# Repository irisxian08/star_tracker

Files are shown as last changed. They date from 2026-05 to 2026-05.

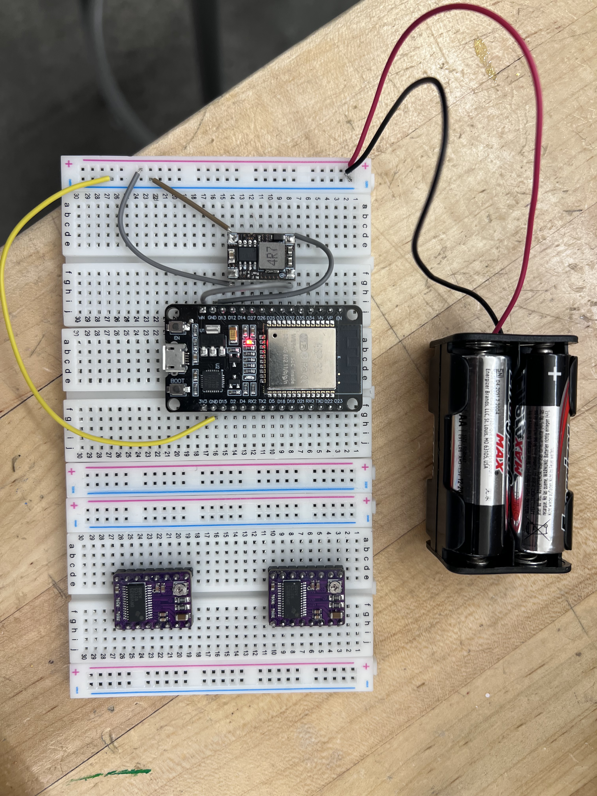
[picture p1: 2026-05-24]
photos/breadboard_testing.jpg

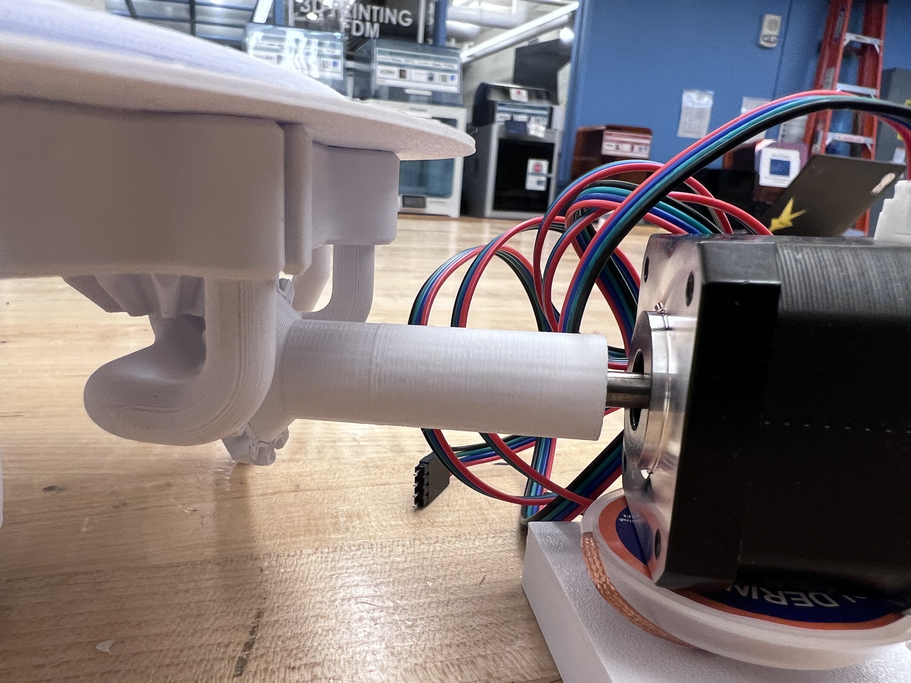
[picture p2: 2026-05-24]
photos/azimuth_motor_close_up.jpg

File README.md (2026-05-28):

# Star Tracker Project

## PLEASE READ BEFORE STARTING PROJECT

---

## Introduction

This project is a motorized alt-azimuth star tracker/pointing system designed to rotate toward celestial coordinates using two stepper motors controlled by an ESP32 microcontroller. The long-term goal is to create a low-cost, modular system capable of automatically pointing a laser (and potentially a camera or telescope) toward astronomical targets using coordinate conversion algorithms and motorized movement.

The project combines mechanical design, electronics, soldering, embedded programming, and astronomical coordinate systems into a single integrated system. While the current version is still a prototype and several hardware issues remain unresolved, the project documents the full design process, including successful subsystems, failed attempts, debugging notes, and lessons learned.

This repository includes CAD models, wiring diagrams, motor-control code, calibration/error-detection ideas, troubleshooting notes, and engineering/design reflections. The goal of the repository is not just to show a finished build, but to document the actual engineering process behind building a system like this from scratch.

---

## Repository Navigation

### Main Files

- [Parts List](parts_list.xlsx)
- [Sources and References](sources.docx)
- [Engineering and Debugging Notes](notes.docx)

### Folders

- [CAD Files](cad_files/)
- [Photos and Build Documentation](photos/)

---

## Components List

See the full components list here:

[Parts List](parts_list.xlsx)

The components document includes:
- part names
- Amazon/product links
- approximate prices
- notes about compatibility
- suggested substitutions and alternatives

The cells colored green in the sources document correspond to especially important resources/components and should be prioritized.

The link to the relevant CAD files can be found here:

[CAD Files](cad_files/)

An electrical diagram can be found in the photos folder.

Please note that the laser used in this project is fairly old and is no longer widely available online. Before purchasing a replacement laser, make sure its dimensions are similar to the dimensions assumed by the laser holder CAD model. Otherwise, the holder may need to be modified slightly in Tinkercad or another CAD software before printing.

---

## Photos and Build Documentation

This folder contains development and assembly images for the star tracker project. The images are intended to document the prototyping and construction process rather than serve as formal assembly instructions.

Included images may show:
- the completed mechanical structure
- close-up views of the rotating turntable assembly
- breadboard testing setups
- the soldered circuit/perfboard assembly
- ESP32 power and testing states
- conceptual diagrams for the altitude rotation system
- internal wiring layouts
- partially assembled prototypes

Many of the images focus on intermediate stages of development and debugging rather than polished final results. The goal is to preserve the engineering process and document how different subsystems evolved throughout the project.

---

## Suggested Workflow

### 1. Learn the Coordinate System First

Before building hardware, it is important to understand the coordinate systems involved and how celestial coordinates translate into physical movement. Much of this project depends on rotational geometry and angular conversion.

Topics worth learning beforehand:
- altitude and azimuth coordinates
- right ascension and declination
- stepper motor stepping/microstepping
- gear ratios and rotational conversion
- basic spherical astronomy concepts

Without understanding the coordinate system, it becomes difficult to debug whether errors are mechanical, electrical, or mathematical.

---

### 2. Test Electronics Individually

**Do not permanently assemble or solder components before individually testing them.**

Recommended order (test using a breadboard):

1. Verify ESP32 connection to the computer
2. Upload a simple LED blink program
3. Test one DRV8825 driver with one motor
4. Verify stepping and direction behavior
5. Confirm stable power delivery from the battery and buck converter
6. Only after successful testing should soldering begin

A major lesson from this project was that debugging multiple unknowns simultaneously becomes extremely difficult once systems are integrated together.

---

### 3. Build the Mechanical Structure Separately

The mechanical structure should initially be tested independently from the electronics.

Important things to test:
- structural rigidity
- friction between moving surfaces
- gear engagement
- axle alignment
- wobble during rotation
- whether the motors can physically support the load

Small alignment problems can create surprisingly large pointing inaccuracies.

---

### 4. Integrate Motors With the Structure

Once the electronics and structure both work independently:

- mount motors onto the structure
- verify full rotational range
- measure actual conversion ratios
- compare expected vs observed movement

The current prototype uses experimentally measured conversion ratios between motor rotation and sky-angle movement. These values are approximate and should be recalibrated for any rebuild.

---

### 5. Implement Calibration and Error Checking

The current prototype uses a simple calibration/error-detection system based on physical angle dials attached to the altitude and azimuth axes. These dials allow comparison between the angle the software expects the mount to rotate and the angle the mount physically rotates in reality.

This is important because the system currently operates with an open-loop logic system. The ESP32 microcontroller assumes the motors successfully completed every commanded step, but there is no built-in way to verify this physically occurred.

Potential causes of error include:
- missed motor steps
- backlash
- structural flexing
- insufficient torque to drive mechanical components
- systematic calibration errors

The dial system provides a low-cost and mechanically simple way to detect these problems during testing.

---

### 6. Keep Extensive Notes

One of the most useful parts of the project ended up being the running engineering/debugging notes document.

The notes include:
- failed experiments
- wiring mistakes
- CAD revisions
- calibration attempts
- power-delivery problems
- design tradeoffs
- lessons learned

Reading these notes before attempting a rebuild is strongly recommended because they contain many practical warnings that are difficult to capture in formal documentation alone.

You can find the notes document here:

[Engineering and Debugging Notes](notes.docx)

---

## Electronics and Soldering Notes

This project involved significantly more hardware debugging than originally expected.

Important recommendations:
- use breadboards to test everything first before soldering
- avoid permanently soldering untested systems
- use common grounding carefully
- double-check DRV8825 orientation before powering
- verify buck converter voltage before connecting the ESP32
- expect electrical debugging to take much longer than anticipated
- be VERY conservative with work plans, since debugging after completion can take twice as much time (or more) than the original work itself

A large portion of the project’s development time was spent diagnosing electrical rather than programming problems.

---

## 3D Printing Notes

The parts for this project were printed primarily using Bambu Lab printers, specifically the X1 Carbon and A1 series printers.

If using different printers, tolerances and dimensions may come out slightly differently. Some parts may require small adjustments, sanding, resizing, or redesign depending on printer calibration and print quality.

Mechanical fit should therefore always be tested before fully assembling the structure.

---

## Using the tracker

The current tracker is set up so that there are two "dials" to help with coordinate verification. The full ring is horizontal (checks azimuth) and the other quarter ring is vertical (checks altitude). A description of the system and how to use it can be found here: [Instructions](using the error-checking system.docx). 

---

## Current Issues

The project is currently incomplete due to unresolved hardware reliability problems.

### 1. Faulty circuit board

The perfboard/circuit assembly may contain unstable or incomplete connections, potentially causing inconsistent power delivery.

### 2. Possible faulty buck converter

The buck converter may not be supplying stable voltage/current under load. This may have contributed to ESP32 instability and inconsistent behavior.

### 3. ESP32 upload/connection problems

The ESP32 occasionally failed to enter proper upload mode and sometimes produced inconsistent serial behavior.

### 4. Motor driver/power uncertainty

There is still uncertainty regarding:
- driver configuration
- stable current delivery
- whether the motors are receiving sufficient power under load

These uncertainties were likely related to the issues described in section 1.

### 5. Mechanical precision limitations

The current gear-driven (azimuth) and tension-driven (altitude) systems are mechanically stable, but there are possible limitations regarding:
- step inconsistencies from gear manufacturing
- string lengthening over time due to continuous tension
- uneven weight distribution affecting smooth azimuthal rotation due to asymmetrical component placement on the turntable plate

### 6. Limited full-system testing

Because several subsystems failed simultaneously, the fully integrated system could not be reliably tested end-to-end.

Even though the final prototype is unfinished, much of the underlying infrastructure, design logic, and testing framework has been developed and documented.

---

## Potential Scale-Up Ideas

### 1. Stellarium Integration

A future version could connect directly to Stellarium so that selecting an object in the planetarium software automatically sends coordinates to the mount.

### 2. Closed-Loop Position Feedback

Future versions could incorporate:
- rotary encoders
- IMUs
- sensor fusion systems

This would allow the system to verify its actual orientation rather than assuming all commanded motor steps succeeded.

### 3. Telescope or Camera Mounting

The current laser-pointer payload could eventually be replaced with:
- a lightweight telescope
- an astrophotography camera
- a tracking camera system

This would require significantly improved structural rigidity and tracking precision but would make the project significantly more applicable to real-world scenarios.

### 4. Automated Object Tracking

The current system mainly focuses on pointing. A future version could continuously track celestial objects over time by dynamically updating motor positions.

---

## Sources + Helpful Links

See the full sources/reference document here:

[Sources and References](sources.docx)

This file contains tutorials, datasheets, astronomy references, ESP32/DRV8825 resources, CAD references, and troubleshooting material that were useful during development.

The cells colored green in the sources document correspond to especially important resources/components and should be prioritized.

Additional debugging notes and lessons learned can be found in the running notes document, which includes warnings, failed experiments, calibration attempts, and practical advice gathered throughout the build process.

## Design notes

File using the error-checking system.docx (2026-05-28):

RA #2

My error-checking plan is to add physical degree dials to both the altitude and azimuth axes of the mount. These dials would act as external references that allow me to compare the angle the software expects the mount to move with the angle the mount actually rotates in real life. Since the system uses stepper motors in an open-loop configuration, the ESP32 assumes the motors successfully completed every commanded step, but it has no built-in method of verifying that this physically occurred. In reality, issues such as friction, slipping, backlash, insufficient torque, poor balance, or missed steps could all cause the mount’s true position to drift away from the calculated position over time.

The dial system gives me a straightforward way to measure and study these errors. To calibrate the mount, I would first align both axes to known zero positions. Then I could command the system to rotate by controlled amounts, for example 10°, 30°, 45°, or 90°, and compare the commanded angle to the value shown on the physical dial after the movement finishes. The difference between these values becomes a measurable rotational error. By repeating these tests many times and across many different angles, I can begin identifying patterns in the system’s inaccuracies.

One implementation detail I needed to account for is that the physical dial design itself wraps from 0° to 90° and then back from 90° to 0°, meaning there are two “0” markings located on opposite sides of the dial. To avoid ambiguity during testing, I marked one of the zeros so that it represents the true 0° reference point, while the opposite side effectively becomes the 180° position. This is a small detail, but it is important because incorrectly reading the dial could introduce measurement mistakes during calibration and testing.

For example, if the mount consistently undershoots by roughly the same percentage, that suggests the software’s step-to-angle conversion is incorrect, meaning the calculations relating motor steps to physical motion need adjustment. If the errors are inconsistent or become worse during faster movements, the problem is more likely mechanical, such as slipping friction wheels, unstable load distribution, excessive resistance, or skipped motor steps. In this sense, the dials are not just measuring accuracy; they help isolate where inaccuracies originate inside the system.

I chose this approach because it prioritizes clarity, controllability, and simplicity during development. More advanced feedback systems certainly exist. Rotary encoders could electronically track shaft rotation, and IMUs could estimate orientation using gyroscopes and accelerometers. However, both options introduce significant additional complexity. Encoders require additional mounting constraints, wiring, signal processing, and interpretation logic, while IMUs suffer from drift, noisy measurements, and filtering problems that often require sensor fusion algorithms. At this stage of the project, adding those systems could make debugging harder rather than easier because errors could come from either the tracking system or the mount itself.

The physical dials avoid this ambiguity because they directly display the mount’s true mechanical position in a way that is visible and immediately understandable. If the code commands a 45° rotation and the dial reads 42°, the discrepancy is obvious and does not depend on interpreting sensor data or trusting another electronic subsystem. This makes the dials especially useful as an early-stage calibration and debugging tool and allows me to validate the core mechanics of the mount before introducing more sophisticated closed-loop feedback systems later on.

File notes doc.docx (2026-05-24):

Legend:

Electric components

Soldering

Organization

Safety notes

Mechanical/CAD

4/7/2026

Most components arrived, could not find header pins, so forced to plan out circuit board by putting available components down

Note that the step-down buck converters come in a connected pack of 5, so you’d have to break them into individual components yourself in order to solder them on

A trick is to solder the female header pins onto the perfboard and solder male header pins onto the electronic components (most already come with those), so you can switch out components whenever you need to (in case some of them break, etc) without having to re-solder anything. The buck converter seem to need to be soldered directly on though; could alternatively solder four male header pins and pair them with four corresponding female header pins (though this is hard to do in practice, since the header pins come in a row of ~20)

Please, before soldering, plan out your circuit on paper! This will help you see what need to be connected to what (in terms of pins) and whether you need to establish “lines” of solder that essentially serves as a giant piece of metal, which is useful for connecting, say, multiple components to the battery

4/8/2026

SOLDER THE WIRES NEXT TO THE DESIRED PIN when possible because this helps with reducing the amount of solder on one pin → less chance of two neighboring pins touching → less chance of a short circuit

It also might be a good idea, when soldering parts directly onto the board, to solder on the wire along with the components, i.e. put the wire through the perfboard hole and the hole of the part you’re trying to solder, bend the exposed metal part of the wire such that both are now attached/hinged about that one hole, solder it on, and then cut off the excess.

→ there is also the added benefit of having a “template” to connect two neighboring perfholes together

PLEASE make sure that the wires have a MINIMAL amount of exposed metal, as that could lead to short circuits later on (if two metal pieces touch when they’re not supposed to → short circuit)!

4/9/2026

Please check before soldering: LONG leg of capacitor = positive, SHORT leg of capacitor = negative! It is very important that you line those up with the power/ground for it to work. In other words, short leg connects to ground, long leg connects to power

Circuit board should be large enough to 1) house all the components and 2) leave at least 3-4 columns of empty holes in between the components. This leaves room for the wires on either side and some wiggle room; capacitors notably must be attached one column away from its neighboring components (simply because it’s big).

Metals get very hot very fast when heated. Use tweezers to hold things in place, or use tape. Avoid holding onto wires, etc. with your hands for too long.

Check the solder pen temperature before you start soldering components onto the board; if the solder is not turning runny almost immediately upon contact with the soldering pen, the temperature is too low! Too low a temperature will result in very jagged solder on the board and possibly impaired functionality (maybe even short circuits).

A trick to solder components onto the board (for things with pins that are hard to bend):

1. Add a bit of solder to one of the holes that the electric component will touch. For instance, if there’s a four-pin header pin you want to attach, pick one of the four holes you’d like to have the pin headers “sit in.”
2. Having the board upright (i.e., the side that all the electric components should be on), heat up the corresponding underside of the board so that the solder you just added is starting to melt.
3. Push the component into the holes; one of the pins of the component should be going through the melted solder.
4. Take the soldering pen away from the board. The solder should solidify and the component is now held in place.
5. Flip the board over (underside, where all the soldering should be done) and proceed normally.

This diagram might be helpful:

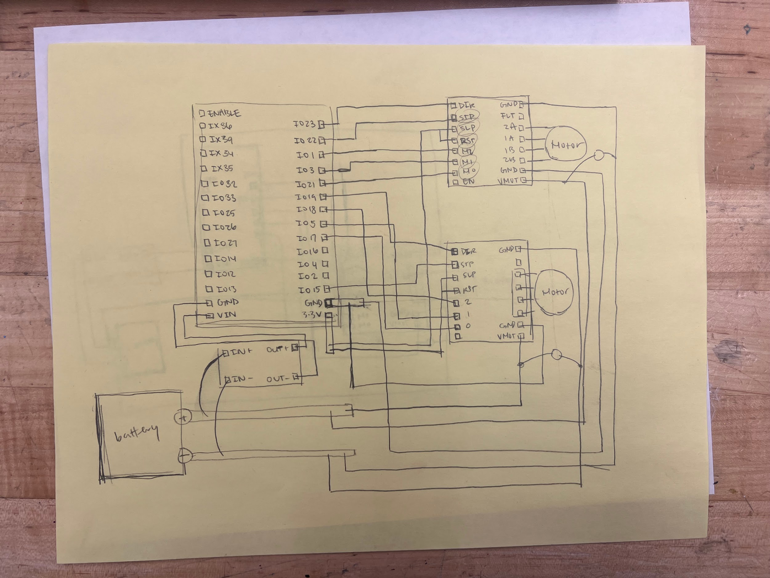
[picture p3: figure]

4/22/2026

Might be a good idea to color code your wires! For instance, use red for power, black for ground, and then, as an example, blue for the DIR pin and yellow for the M0-M2 pins.

Please measure everything first before committing with a 3D print! I personally did not do this my first time CADing and then I ended up with printed parts that were just way too small for my electric components. Sometimes the values given on, say, Amazon are a bit too small and so if you go directly with that without measuring yourself, you could be very off.

Another trick to solder components (particularly wires, etc that are very flexible):

1. Have the wire (exposed parts, or as I like to call it, the “feet” of the wire) go through the holes you want to solder. You can leave them pretty long, as you will be able to clip them once you’re done.
2. Bend the tips of the wires so that the wire is locked in place and won’t fall out when you flip the board over to expose the underside/side you want to add solder to
3. Solder as normally!
4. Clip the excess metal after you’re done.

Also a good idea to prototype with cardboard before you commit to printing

4/23/2026

When there is a 3D print design you have in mind, look on websites like Thingverse first to see if people have already created similar models. If they do exist, this will save you a ton of time (especially considering you could just remodel certain parts to better fit your need); if they are similar but not too relevant to your project, you at least get a sense of what other people’s designs look like, which may give you good inspiration for your own designs.

At the end of every work session, write some short bullet points on what you achieved that day, any setbacks you experienced, and any difficulties or problems (and whether those have been resolved). I think this will give you a nice record of the outstanding work and what’s been completed, which could come in handy when you take a break from working on the project and want to come back to it a few days later. This will also help you communicate with others (experts) who might be able to help you in a specific issue, since it’s important you can explain yourself clearly.

5/12/2026

Before you solder anything…check GPIX vs GPIO pins and know where they are. Some pins are input only (GPIX) and thus are not good for motor drivers.

Check if any of the components need to have heat sinks added to them! This will help ensure that the components work correctly and last for a longer time, since it is very common that electric components get “fried” if they get too hot. There is a special adhesive you’ll need to use, so be sure to check those out too.

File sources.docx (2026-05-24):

Datasheets

ESP32 devkit v1 datasheet:

https://www.circuitstate.com/pinouts/doit-esp32-devkit-v1-wifi-development-board-pinout-diagram-and-reference/

- Here, you can find all the pins and what they do on this specific microcontroller. Make sure that the orientation of your board aligns with the image when planning out the circuit (to avoid incorrect wire connections).
- Note that the 3V3 pin could either be an input (can take in 3.3V) or an output (of 3.3V).

NEMA 17 motor data sheet:

https://media.pbclinear.com/pdfs/pbc-linear-data-sheets/data-sheet-stepper-motor-support.pdf

- I think the most useful information here is the dimensions of the motor.
- Reference these values when designing the physical components of the star pointer.

DRV8825 motor driver data sheet:

https://www.ti.com/lit/ds/symlink/drv8825.pdf?ts=1774764489154&ref_url=https%253A%252F%252Fwww.google.com%252F

- There is a microstepping table in this sheet (page 13) that might come in handy.
- Microstepping allows the motor to move in half-steps, quarter-steps, etc. which will help with the accuracy of our star pointer.

DRV8825 pins and functions:

https://www.flywing-tech.com/blog/drv8825-stepper-motor-driver-guide-pinout-features-cnc-use/

- This gives a good overview of what each pin does in the DRV8825
- Can supplement it with the “Wiring DRV8825 to Arduino” video

Tutorials

Wiring a DRV8825 to Arduino (useful reference when soldering):

https://www.youtube.com/watch?v=J-8_txDnS3w

- I looked at this video to get a gist of how DRV8825 is supposed to work, what pins should be connected where, etc.
- Even though the video uses an Arduino, the underlying concepts are very similar (for instance, the DIR, or direction pin, controls the direction in which the motor rotates and hence should be connected to an I/O pin on the microcontroller).
- Cross-referencing this video and the ESP32 datasheet linked above can help with understanding/planning out this part of the circuit.

OnShape tutorials

- Drawing a rectangle: https://youtu.be/OoZBir2fbko?si=Jx3ou7hKfx53814F
- Drawing a circle: https://www.youtube.com/watch?v=DwMVdVO0yLs
- Helpful beginner tutorial: https://www.youtube.com/watch?v=pMWnsHpDlQE
- I have, in many cases, found it to be helpful to just figure things out myself, but these videos will hopefully help you get reasonably comfortable with OnShape to explore more of its functionalities.

Mechanical Design

Modeling with 3D Printing in Mind:

https://help.prusa3d.com/article/modeling-with-3d-printing-in-mind_164135?

- This article goes over how to design parts specifically for FDM 3D printing, including things like tolerances, clearances, and print orientation.
- It’s useful for understanding why parts that “fit” in CAD might not fit after printing, and how to adjust designs to account for that.

Testing & improving tolerances:

https://all3dp.com/2/3d-printing-tolerances-test-fdm/

- This guide explains how to use small test prints to determine how much clearance your printer actually needs for different types of fits.
- Instead of printing full parts immediately, you can test small sections first to avoid wasting time and material on parts that don’t fit.

Thingverse designs

Turntable:

https://www.thingiverse.com/thing:3723618

- Modified this to make it into the azimuthal control system
- Also houses part of the altitude control system

The parts I designed myself, along with parts that I found online, will all be included in a folder

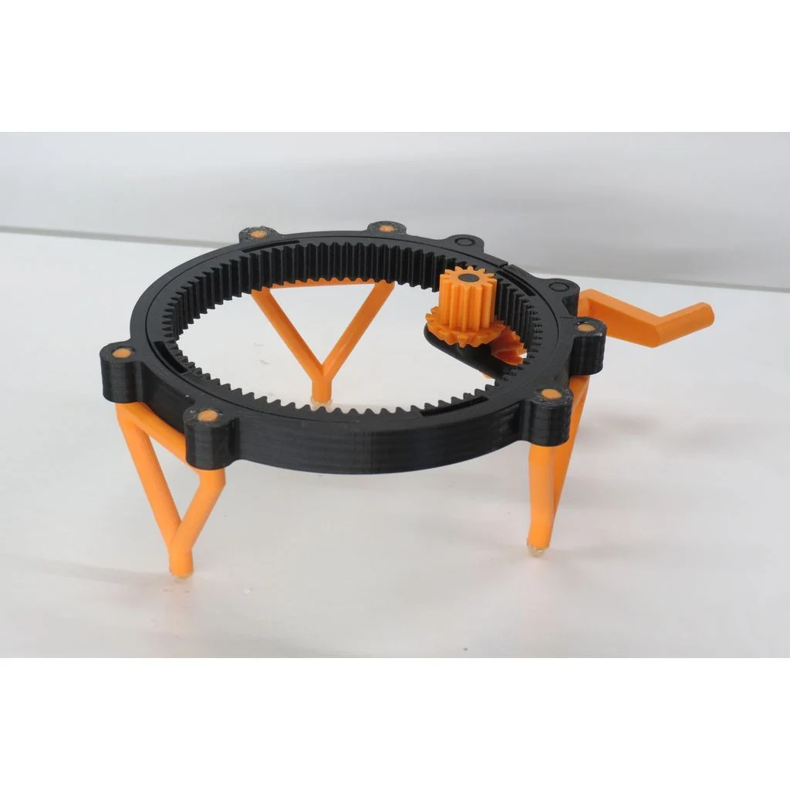
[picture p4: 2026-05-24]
photos/turntable_structure.webp

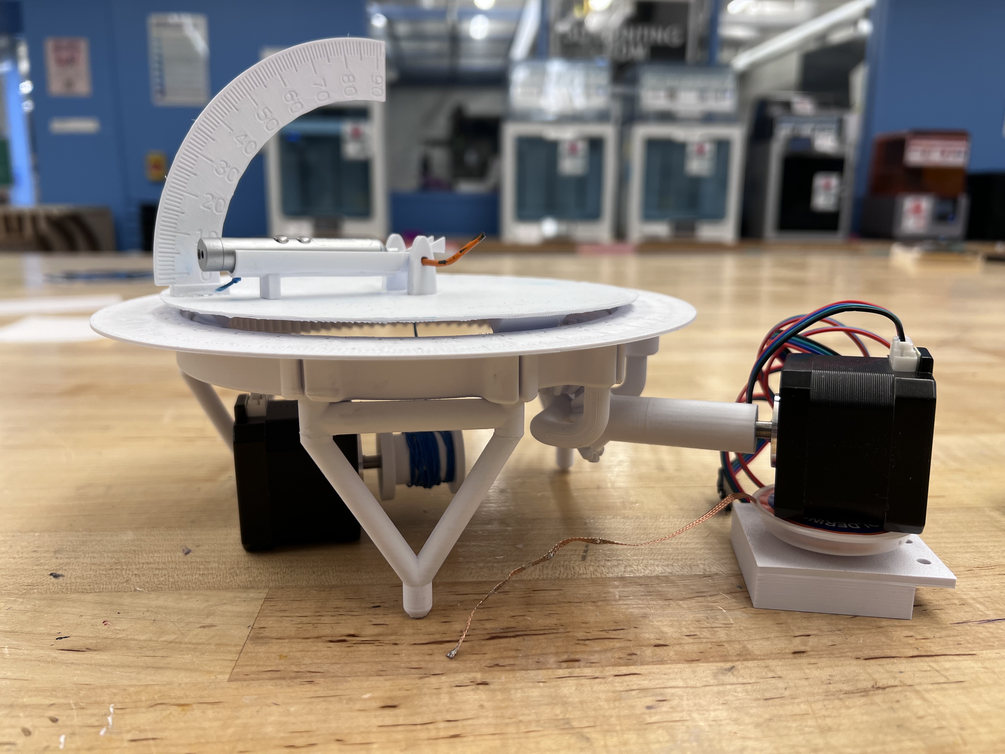
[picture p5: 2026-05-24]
photos/side_view_with_motors.jpg

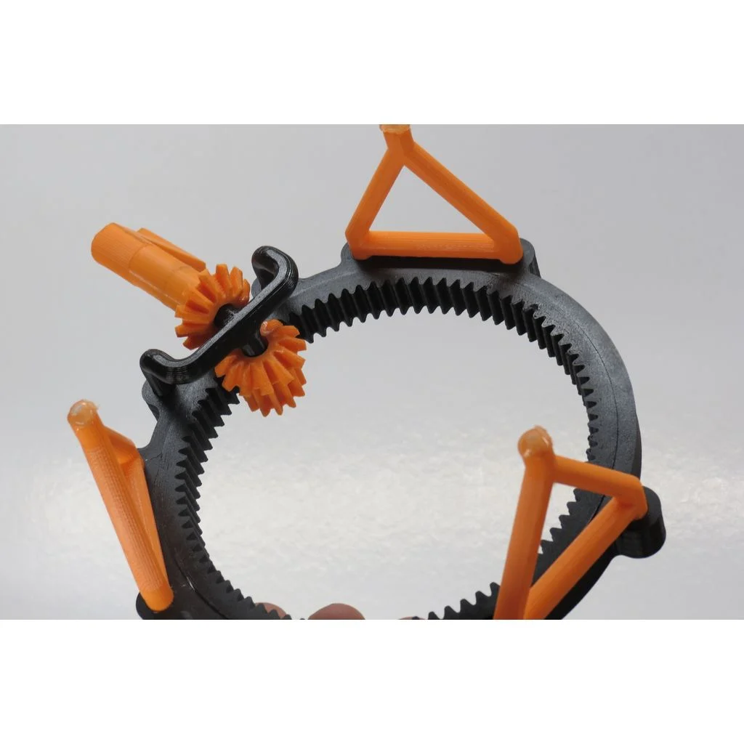
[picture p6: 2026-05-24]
photos/turntable_underside.webp

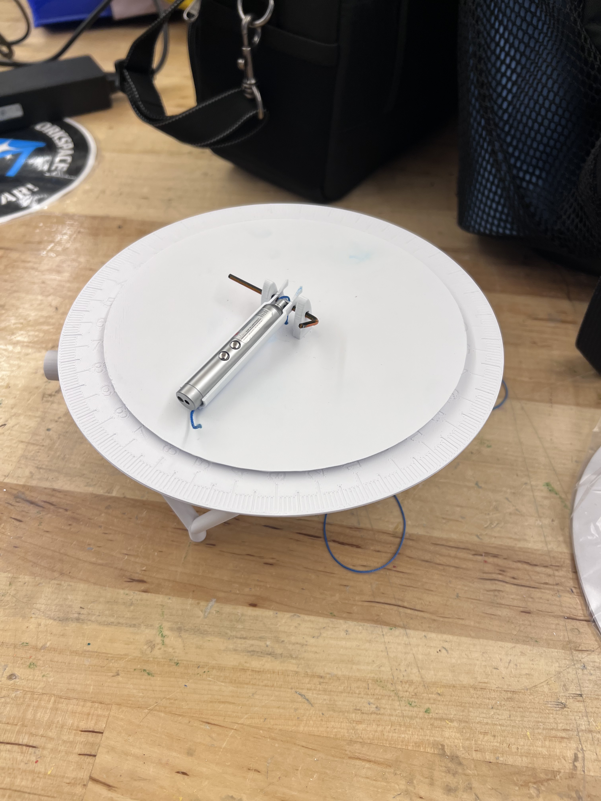
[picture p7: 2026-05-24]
photos/top_view_turntable.jpg

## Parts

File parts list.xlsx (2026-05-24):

Things I bought | amazon link | potentially better alternatives | Things I already had and didn't buy but are used in this project | amazon link | notes
ESP32, 3-pack | price: $15.99 (I recommend getting the usb-c version) (https://www.amazon.com/Hosyond-ESP-WROOM-32-Development-Microcontroller-Compatible/dp/B0C7C2HQ7P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) |  | laser | price: $6.28 (https://www.amazon.com/CHUQIANTONG-Pointer-Flashlight-Interactive-Indoor/dp/B09NFSLNWL)
NEMA17 motors, 3-pack | price: $25.99 (https://www.amazon.com/STEPPERONLINE-Stepper-Bipolar-42x42x38mm-Connector/dp/B0B38GHRH8) |  | button batteries | price: $6.29 (https://www.amazon.com/dp/B0BKZW459C?sp_csd=d2lkZ2V0TmFtZT1zcF9kZXRhaWxfdGhlbWF0aWM)
DRV8825 drivers, 5-pack | price: $13.99 (https://www.amazon.com/Teyleten-Robot-Printer-DRV8825-StepStick/dp/B0CP92T4QR) |  | perfboards | price: $9.99 (https://www.amazon.com/WWZMDiB-Circuit-Protoboard-Soldering-Arduino/dp/B0CMZL4T6J?s=electronics)
buttons, 5-pack | price: $6.49 (https://www.amazon.com/DIYables-Button-Arduino-ESP8266-Raspberry/dp/B0BXKN4TY6) |  | soldering pen | price: $26.99 (https://www.amazon.com/Larlarsa-Soldering-Rechargeable-Electronics-Lead-Free/dp/B0F314B4N4)
battery | price: $32.99 (https://www.amazon.com/TalentCell-Rechargeable-12000mAh-Multi-led-indicator/dp/B00ME3ZH7C?s=electronics) | 9V battery + adapter cord (https://www.amazon.com/Amazon-Basics-Performance-All-Purpose-Batteries/dp/B00MH4QM1S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) | solder wire | price: $7.26 (https://www.amazon.com/MAIYUM-63-37-Solder-Electrical-Soldering/dp/B075WB98FJ) | many choices. in my opinion, tin+lead or just tin doesn't make a huge difference.
battery adapter | price: $4.19 (https://www.amazon.com/Connector-Barrel-Adapter-Security-Camera/dp/B09S3S6RYC?nsdOptOutParam=true) |  | wires | price: $15.99 (https://www.amazon.com/gp/aw/d/B07TX6BX47/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)
5V buck converter | price: $8.69 (https://www.amazon.com/Converter-Step-Down-Regulator-Arduino-Electronics/dp/B0F1WB3LJ5) | adafruit 5v buck converter (https://www.adafruit.com/product/4739) | wire peeler | price: $4.59 (https://www.amazon.com/XUDYVCO-Generation-Multifunctional-Electrician-Sharpening/dp/B0DLRMHKZT)
right angle female connectors | price: $9.99 (https://www.amazon.com/Xiaoyztan-Female-Headers-2-54mm-Connectors/dp/B08X374GFR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) |  | header pins | price: $7.49 (https://www.amazon.com/2-54mm-Breakaway-Female-Connector-Arduino/dp/B01MQ48T2V?sp_csd=d2lkZ2V0TmFtZT1zcF9hdGY)
male to female cable | price: $7.88 (https://www.amazon.com/3-3ft-2pcs-5-5x2-1mm-Extension-Connector-Projectors/dp/B0D28T3PTM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) |  | desoldering wick (solder remover) | price: $6.99 (https://www.amazon.com/Lesnow-No-Clean-Desoldering-Removal-Dispenser/dp/B094GZ6CPZ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) | not a must, but good to have to undo mistakes
USB C cable | price: $3.99 (https://www.amazon.com/Charger-Braided-Charging-Compatible-Samsung/dp/B0794M53HQ) |  | breadboards | price: $6.83 (https://www.amazon.com/Breadboards-Solderless-Breadboard-Distribution-Connecting/dp/B07DL13RZH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)

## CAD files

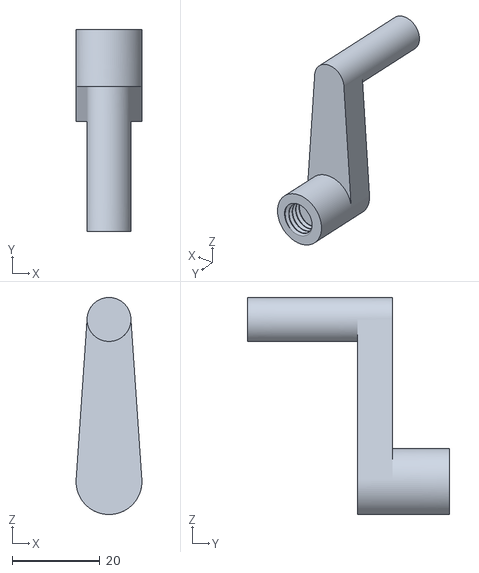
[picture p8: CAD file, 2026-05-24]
cad files/handle_V2.stl
15.0 x 46.0 x 49.4

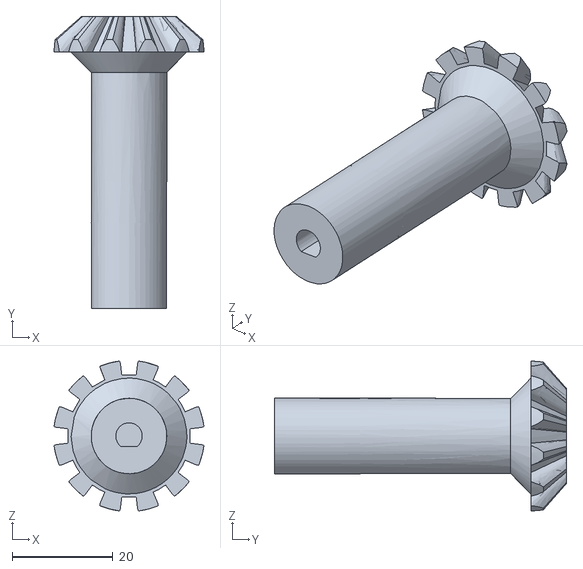
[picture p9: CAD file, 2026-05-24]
cad files/big_gear_modified.stl
29.8 x 58.0 x 29.8

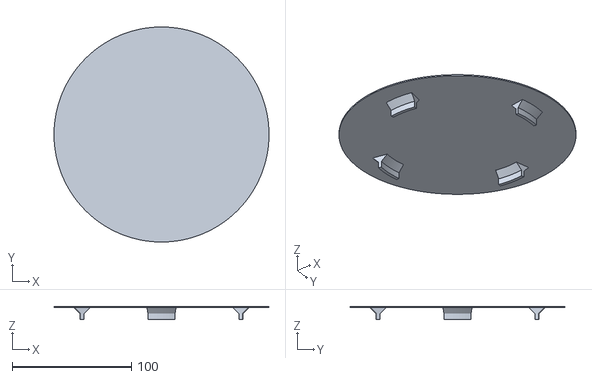
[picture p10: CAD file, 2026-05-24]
cad files/plate_V1.stl
180.0 x 180.0 x 11.0

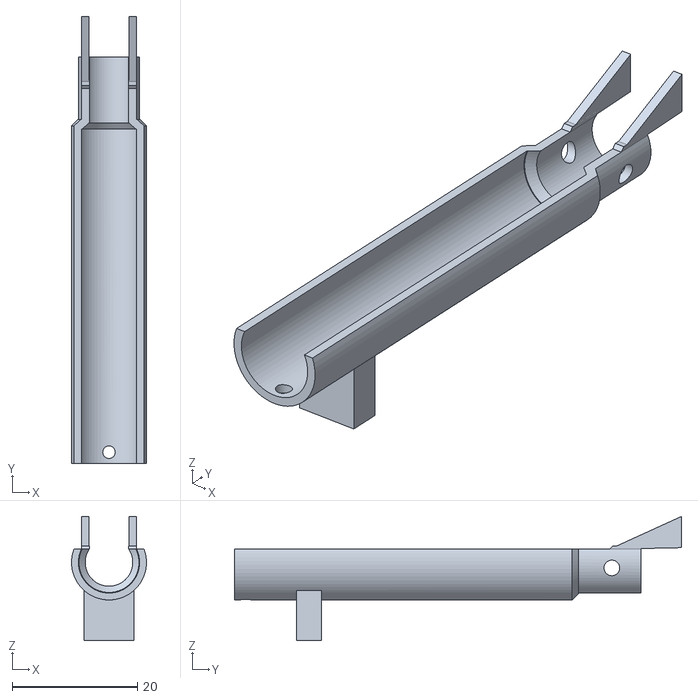
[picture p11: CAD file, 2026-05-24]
cad files/laser_holder.stl
12.0 x 71.5 x 19.9

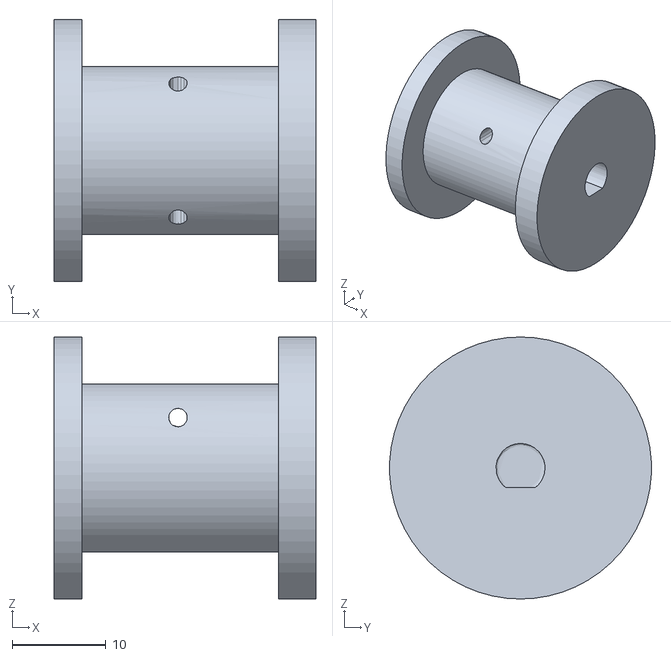
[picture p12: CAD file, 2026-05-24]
cad files/wind_drum.stl
28.0 x 28.0 x 28.0

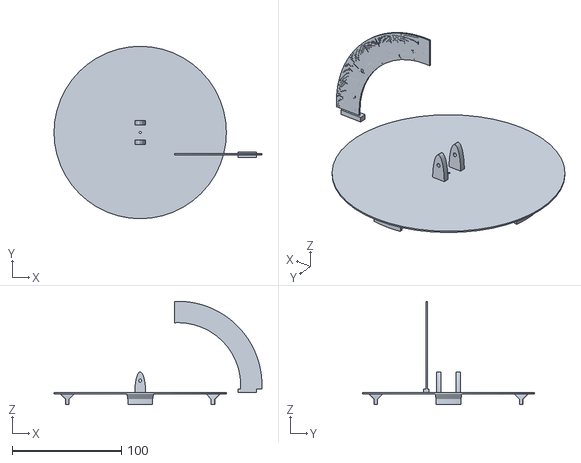
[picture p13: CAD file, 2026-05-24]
cad files/turning_plate.stl
190.0 x 157.5 x 94.5

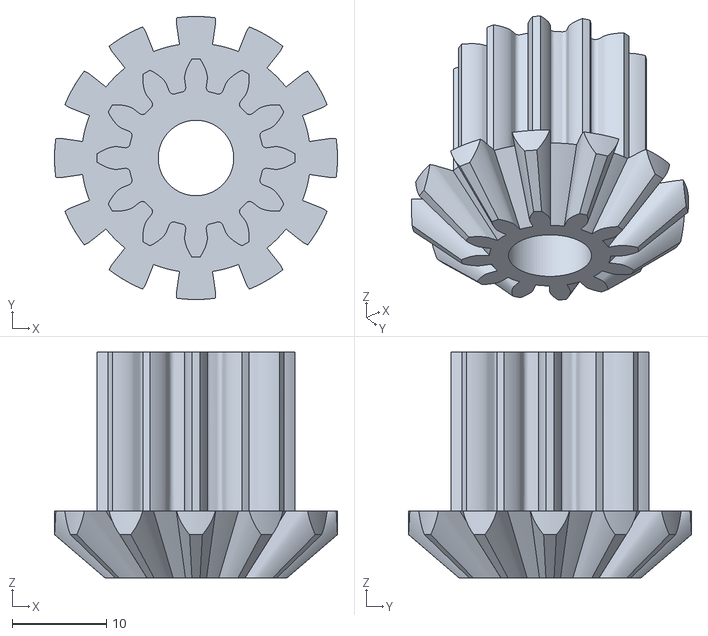
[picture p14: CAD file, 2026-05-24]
cad files/small_gear_V2.stl
30.0 x 30.0 x 23.9

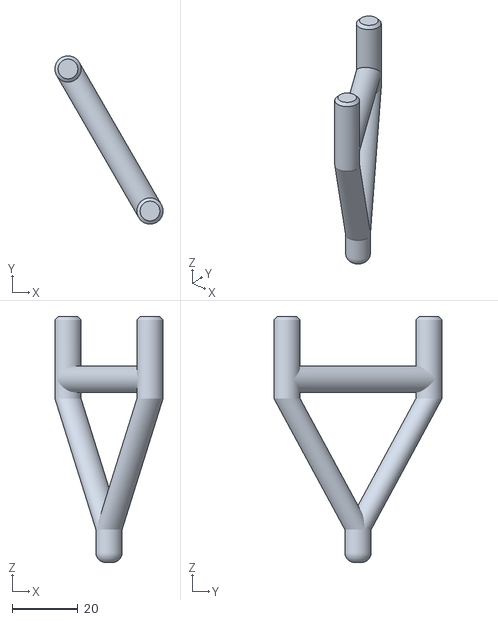
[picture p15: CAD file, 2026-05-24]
cad files/Leg_V2.stl
33.0 x 51.3 x 75.0

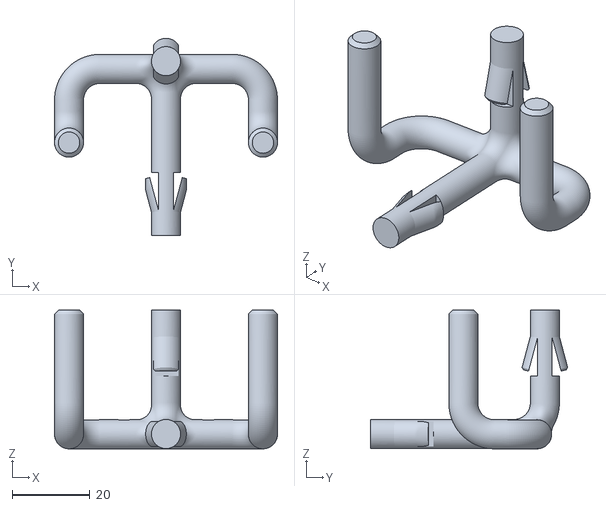
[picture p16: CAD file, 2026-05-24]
cad files/plumbing_V3.stl
57.5 x 50.9 x 35.7

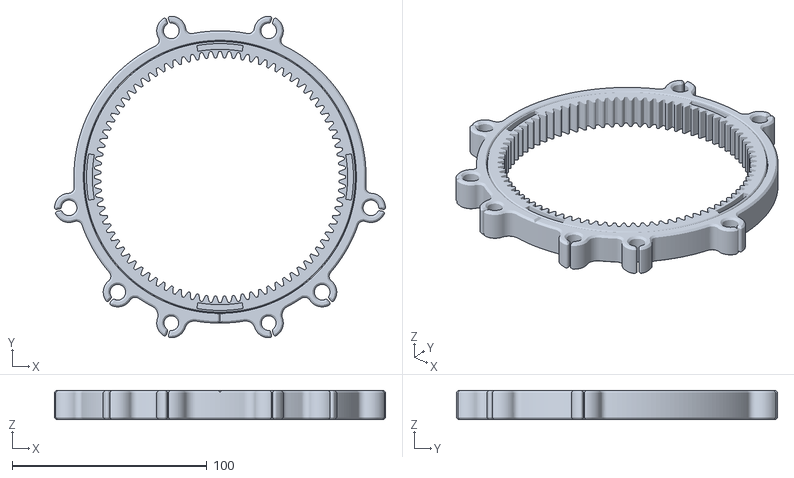
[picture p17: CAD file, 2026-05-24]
cad files/slide_bearing_V3.stl
169.9 x 165.0 x 15.0

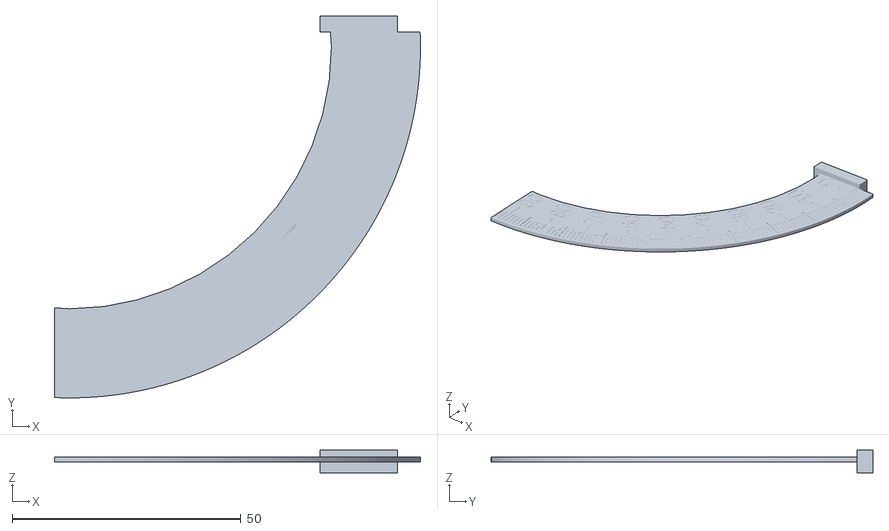
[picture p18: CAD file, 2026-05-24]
cad files/altitude_checker.stl
80.0 x 83.5 x 5.00

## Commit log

2026-05-24 Add CAD instructions for star tracker assembly
    Added instructions for CAD files related to the mechanical structure of the star tracker, including printing notes and subsystem details.
2026-05-24 Added CAD files for the project
    [Leg_V2.stl, altitude_checker.stl, big_gear_modified.stl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]
2026-05-24 Add overview documentation for star tracker images
    This folder contains images documenting the development and assembly of the star tracker project, including mechanical structures and testing setups.
2026-05-24 Add detailed README for Star Tracker Project
    This README provides a comprehensive overview of the Star Tracker Project, including its purpose, components, workflow, and current issues. It also contains links to important documents and resources for further reference.
